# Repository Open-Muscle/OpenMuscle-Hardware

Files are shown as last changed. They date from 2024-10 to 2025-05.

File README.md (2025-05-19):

# 🛠️ OpenMuscle-Hardware (Deprecated)

> ⚠️ **This repository is no longer maintained.**  
> All hardware design files have been **moved to dedicated repositories** for each OpenMuscle device.  
> Please use the links below to access the latest versions, schematics, and BOMs.

---

## 📦 Where to Find Active Repositories

| Device | Description | New Repo |
|---|---|---|
| **FlexGrid** | 60-sensor modular wearable (successor to OM-12) | [OpenMuscle-FlexGrid](https://github.com/Open-Muscle/OpenMuscle-FlexGrid) |
| **LASK5** | Handheld labeler wand for gesture training | [OpenMuscle-LASK5](https://github.com/Open-Muscle/OpenMuscle-LASK5) |
| **OM-12** | Legacy 12-sensor forearm band | [OpenMuscle-Band](https://github.com/Open-Muscle/OpenMuscle-Band) |
| **Firmware & Scripts** | MicroPython code for all devices | [OpenMuscle-Software](https://github.com/Open-Muscle/OpenMuscle-Software) |
| **Documentation** | Central hub with build guides & tutorials | [OpenMuscle-Hub](https://github.com/Open-Muscle/OpenMuscle-Hub) |

---

## 🧬 About This Repo

This repository originally contained hardware design files for two experimental devices:

- **OpenMuscle Labeler** – A handheld interface for labeling finger positions in machine learning datasets.
- **OpenMuscle Sensor Bracelet (OM-12)** – A pressure-based forearm sensor for capturing muscle signals.

These designs are preserved in their new locations above for better modularity and long-term maintainability.

---

## 🧾 Historical Reference

This repo includes:
- `Labeler/`: KiCad files and documents for early LASK prototypes
- `SensorBracelet/`: KiCad files and mechanical designs for OM-12
- `docs/`: Revision notes and changelogs

---

## 📜 License

This repository is licensed under the **CERN-OHL-S v2** (Strongly Reciprocal).

"""markdown
🔗 Learn more at the [Open Source Hardware Association (OSHWA)](https://www.oshwa.org/definition/)
"""

OpenMuscle is an OSHWA-Certified open hardware project  
**Certification UID:** US002537

---

## 🙌 Thank You

Thank you to everyone who starred, forked, contributed to, or studied this repository during its development phase.  
Please visit the [OpenMuscle GitHub Organization](https://github.com/Open-Muscle) to explore the new, modular layout and latest devices.

🧠 Built by [@TURFPTAx](https://github.com/turfptax) • Project home: [openmuscle.org](https://openmuscle.org)

## 🎥 Video Overview

Curious about the assembly process? Watch our detailed video guide covering both the Sensor Bracelet (OM-12) and Labeler (LASK5) builds:  
📺 **[Watch on YouTube](https://www.youtube.com/watch?v=DQQq6cplsOw)**

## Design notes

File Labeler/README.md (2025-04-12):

# LASK5 - A Gloveless Smart Glove Controller





LASK5 is a compact, gloveless smart glove controller designed for robotics, machine learning, and human-computer interaction projects. Originally created to assist with labeling movement data for the [OpenMuscle](https://openmuscle.org) project, this controller is now a fully open-source interface capable of controlling robotic hands, LED sculptures, and more.

---

## 📽️ Watch the Demo

🎥 **YouTube Video:** [LASK5: The Gloveless Smart Glove](https://youtu.be/DJxaf0ww6us)

---

## 🔧 Features

- ESP32-S3 based (Wi-Fi + ESP-NOW enabled)
- 4-piston finger input with hall sensors
- Thumb joystick
- 128x32 OLED display for menus and feedback
- 4 SMD buttons for UI control
- Modular headers for add-ons (gyroscope, additional sensors)
- Written in MicroPython
- 3D-printable enclosure

---

## 📁 Repository Structure

This repo is split into two main components:

### 🛠️ Hardware
📂 [OpenMuscle-Hardware → Labeler](https://github.com/Open-Muscle/OpenMuscle-Hardware/tree/main/Labeler)  
Includes schematics, board files (KiCad), and 3D printable STL files.

### 💾 Software
📂 [OpenMuscle-Software → embedded/Labeler](https://github.com/Open-Muscle/OpenMuscle-Software/tree/main/embedded/Labeler)  
Includes MicroPython source code and menu system.

---

## 🧠 Use Cases

- Robotics hand control (e.g., HiWonder robotic hand)
- LED and art installations
- Machine learning data labeling
- Experimental HCI and VR interface development

---

## 🚀 Getting Started

1. Clone the hardware and software repos.
2. Flash the ESP32-S3 with the provided MicroPython firmware.
3. Assemble the hardware using the STL and PCB files.
4. Power it up and start controlling your devices wirelessly via ESP-NOW!

---

## 🤝 Contribute

Got improvements, ideas, or bug fixes? PRs are welcome!  
If you're using this for your own project, we'd love to see it—tag [@OpenMuscle](https://openmuscle.org)!

---

## 📜 License

This project is open-source and licensed under the MIT License.

---

Made with 💡 by [TURFPTAx](https://github.com/turfptax) for the [OpenMuscle](https://openmuscle.org) initiative.

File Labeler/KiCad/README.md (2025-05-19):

# LASK5 – OpenMuscle Sensor Device

**Version:** `V3 (Proposed)`  
**Target Microcontroller:** ESP32-S3-WROOM-1-N16R8  
**Project:** OpenMuscle – Biomechanical Sensing for Prosthetics & Robotics  
**Repository:** https://github.com/turfptax/OpenMuscle-Hardware

---

## 📐 Overview

The LASK5 board is a wearable sensor platform for real-time finger movement detection, developed as part of the OpenMuscle project. It integrates Hall effect sensors, a joystick, buttons, a low-power screen, and wireless communication via ESP32-S3.

Version 3 introduces multiple improvements in usability, sensing accuracy, and expandability.

---

## 🚀 New in V3 (Proposed)

| Feature | Description |
|---|---|
| 🔌 USB Detection | VBUS now routed to a GPIO via voltage divider, allowing firmware to detect USB connection. |
| 🔋 USB Boot Without Battery | Modified power logic enables powering on via USB without a battery installed, using diode-based OR logic to control LDO enable line. |
| 📉 Improved ADC Accuracy | Voltage divider for battery monitoring updated to 10k/10k, reducing impedance for better ESP32-S3 ADC readings. |
| 🧭 6-Axis Gyroscope Support | IMU footprint and I²C headers added for optional motion sensing (MPU6050 or ICM-42688). |
| ⚙️ Charging Status Feedback | CHRG pin from LTC4054 connected to GPIO for in-software charge status indication. |

---
## 📦 Block Diagram
```
Battery ─────┐
├─> Charger (LTC4054) ──> Power Rail (+3.3V)
USB ───────┐ │
│ └─> VBUS GPIO (USB Detect)
└───> LDO EN Logic ──> TPS7A0333 LDO ──> ESP32-S3
```
---

## 📊 Hardware Specifications

- **MCU:** ESP32-S3-WROOM-1-N16R8 (dual-core, WiFi/BLE, 16MB flash, 8MB PSRAM)
- **Power:**
  - USB-C with VBUS detection
  - 1-cell LiPo battery
  - TPS7A0333 LDO (3.3V, low quiescent current)
  - MAX16054 latched soft-power button
- **Sensing:**
  - 4x Hall effect analog sensors
  - 1x Joystick (XY + button)
  - 0.96” SSD1306 OLED display (I²C)
  - Optional 6-axis gyro (MPU6050, ICM-42688, etc.)
- **Inputs:**
  - `menu` and `select` tactile buttons
  - Power button
- **Charging:**
  - LTC4054ES5-4.2 Li-Ion charger
  - CHRG status indicator routed to GPIO
- **Communication:**
  - ESP-NOW, WiFi, BLE
- **Headers:**
  - I²C breakout
  - SPI/debug/jumper expansion

---

## 🛠️ Setup & Firmware

- Flash via USB-C using esptool or Micropython.
- Default I²C pins: `SDA=GPIO15`, `SCL=GPIO16`
- ADC battery read: `GPIO4` (adjusted via voltage divider)
- USB detect pin: `GPIO10` *(example)*
- CHRG detect pin: `GPIO11` *(example)*

---

## 📚 Resources

- [OpenMuscle.org](https://openmuscle.org)
- [KiCad Schematic Viewer](https://kicad.org)
- [ESP32-S3 Datasheet](https://www.espressif.com/sites/default/files/documentation/esp32-s3_datashee---

## 🙌 Contributing

Interested in testing or improving the hardware? Submit a pull request or open an issue with your suggestions.

---

## 🧪 Version History

| Version | Date | Notes |
|---|---|---|
| V1 | 2024-02 | Initial prototype, using ESP32-S3 Dev-Kit |
| V2 | 2024-05 | 4-Layer PCB with 4x1 Hall sensors & Joystick |
| V3 | 25-XX | USB logic, gyro, and ADC improvements |

---

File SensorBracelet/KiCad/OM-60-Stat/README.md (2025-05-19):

# OpenMuscle FlexGrid (v2.0)

**OpenMuscle FlexGrid** is a modular wearable sensor grid with 60 analog pressure sensors arranged in a 15x4 matrix. It is the second-generation wearable in the OpenMuscle series and serves as the core interface for capturing muscle movement in prosthetic and robotics applications.

📍 Project Page: [openmuscle.org](https://openmuscle.org)

---

## 📐 System Overview

- **Sensor Grid**: 15 columns × 4 rows of Velostat pads
- **Flex PCB**: Thin and wearable with 21-pin output header
- **Rigid PCB**: ESP32-S3, haptic feedback, USB-C charging, multiplexer, OLED, IMU

---

## 🔧 Key Features

| Feature | Description |
|---|---|
| MCU | ESP32-S3 (USB + BLE + ADC1) |
| Sensor Matrix | 15×4 Velostat with voltage divider setup |
| Multiplexer | 74HC4067 (16-channel, 15 used) |
| Row Reads | 4x analog inputs on ADC1 |
| OLED Display | SSD1306 128x32 over I2C |
| IMU | ICM-42688-P 6-DOF sensor (optional) |
| Haptic Feedback | Motor driven by IRLML2060 MOSFET |
| Power Management | MAX16054 soft latch, TPS7A0333 LDO, LTC4054 LiPo charger |

---

## 🗂️ File Structure

```graphql
FlexGrid/
├── KiCad/ # Schematic and layout files
├── Images/ # Renders and photos
├── BOM.xlsx # Bill of materials (optional)
└── README.md # You're reading it!
```

# 📁 Repository Layout

```graphql
OpenMuscle-FlexGrid/
├── firmware/           # MicroPython or C code for scanning and I/O
├── hardware/
│   ├── KiCad/          # Schematics, PCB, BOMs
│   └── Images/         # Renders and assembly diagrams
├── docs/
│   └── Datasheets/     # ICs and reference materials
└── README.md
```
---

## 🛠️ How It Works

The 74HC4067 connects one column at a time to 3.3V. The Velostat pads act as pressure-sensitive resistors connected to row lines, which are pulled down with 10kΩ resistors and read via analog inputs.

A software loop cycles through all 15 columns, sampling all 4 rows each time for 60 total readings per frame.

---

## 🧪 Status

- ✅ Schematic Complete
- ✅ PCB Fabricated & Assembled
- 🛠️ Firmware In Progress
- 🧠 ML Integration Pipeline Active

---

## 🔗 Related Projects

- [SensorBracelet (OM-12)](../SensorBracelet/)
- [Labeler (LASK5)](../Labeler/)

---

## 📝 License

- **Hardware**: CERN-OHL-P v2
- **Software/Firmware**: MIT

---

## 🤝 Get Involved

We welcome contributions, feedback, and forks. This project is part of a broader mission to open-source biomechanical sensing tools for all.

Visit **[openmuscle.org](https://openmuscle.org)** or join our Discord (link coming soon).

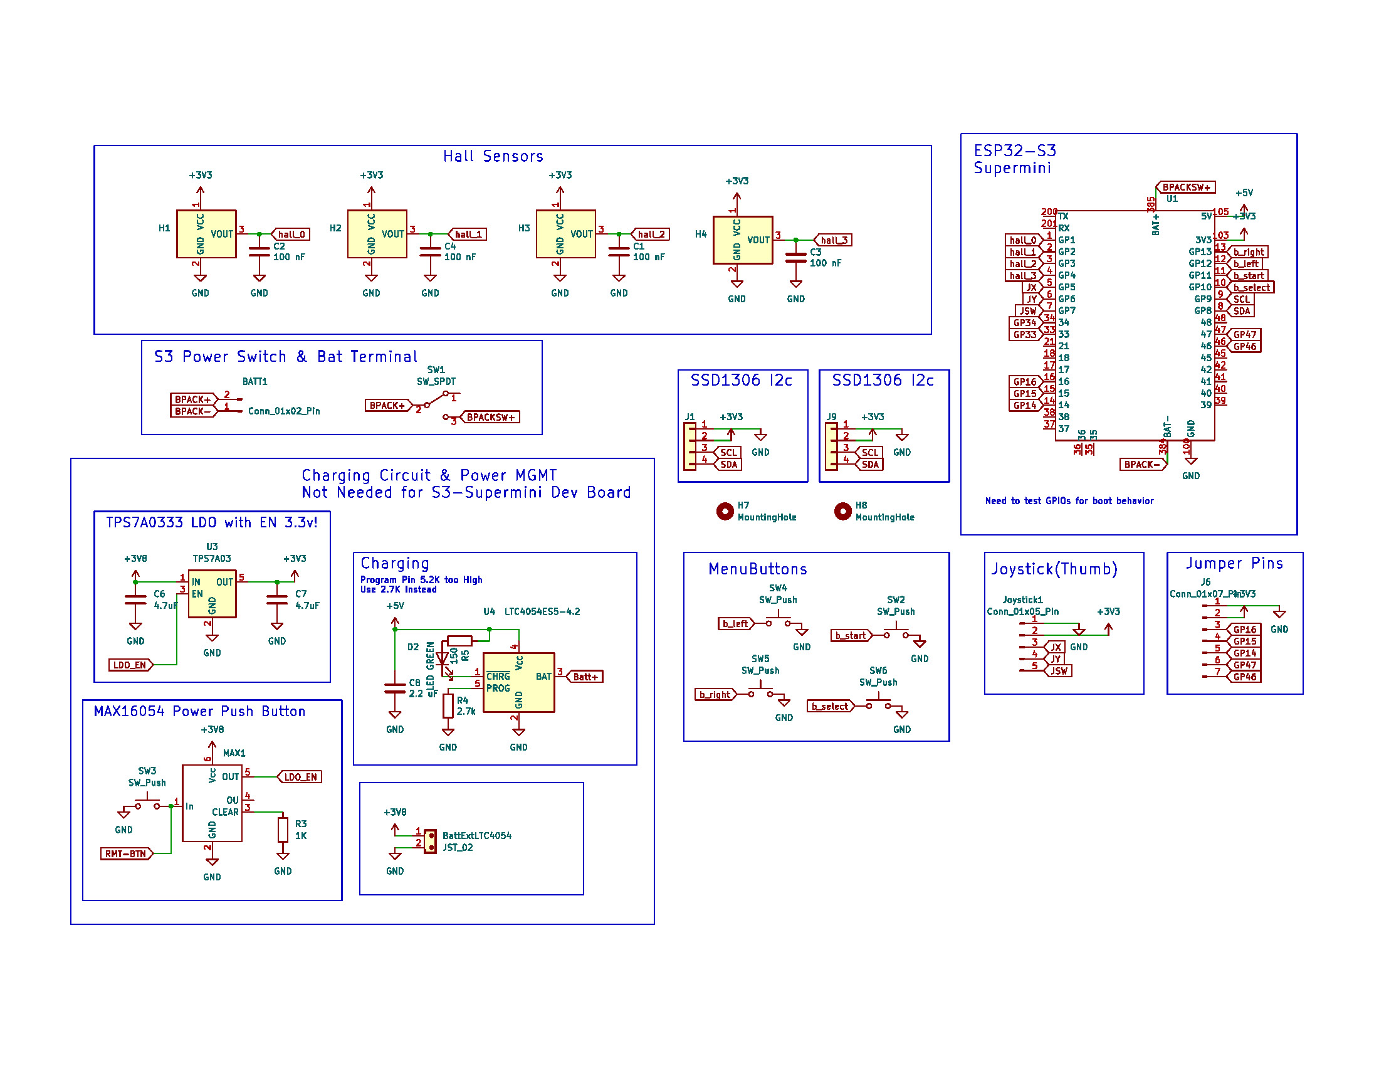
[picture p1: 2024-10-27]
Labeler/Schematics/Open Muscle Labeler (LASK5) Schematic.jpg

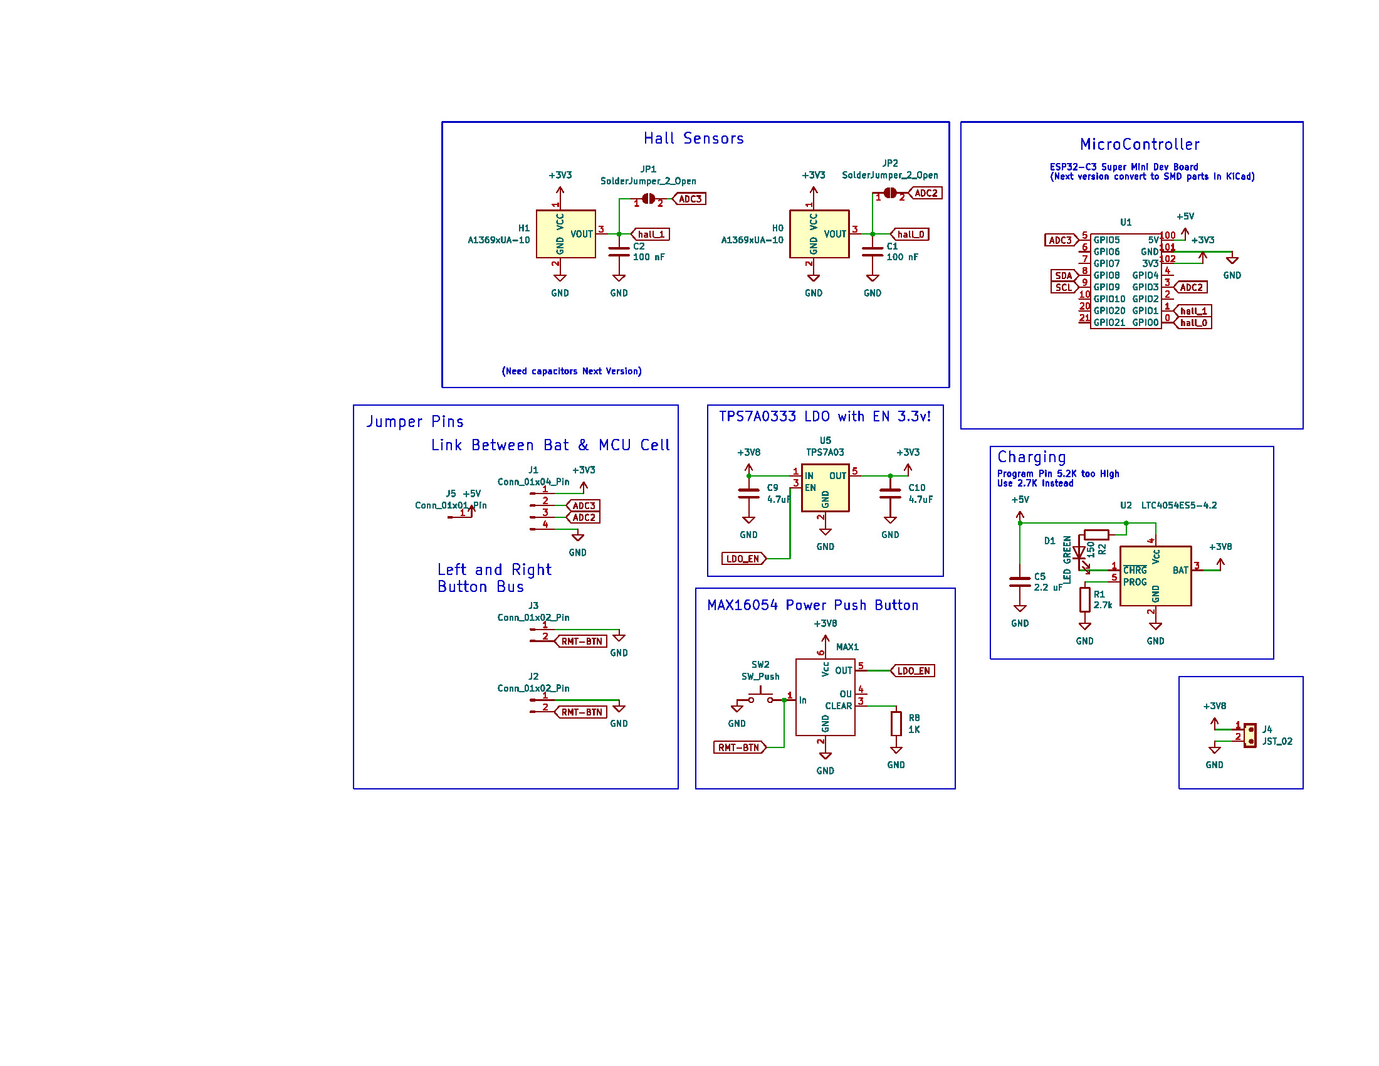
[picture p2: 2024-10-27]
SensorBracelet/Schematics/Open Muscle Dev Kit Bracelet Cell Schematic.jpg

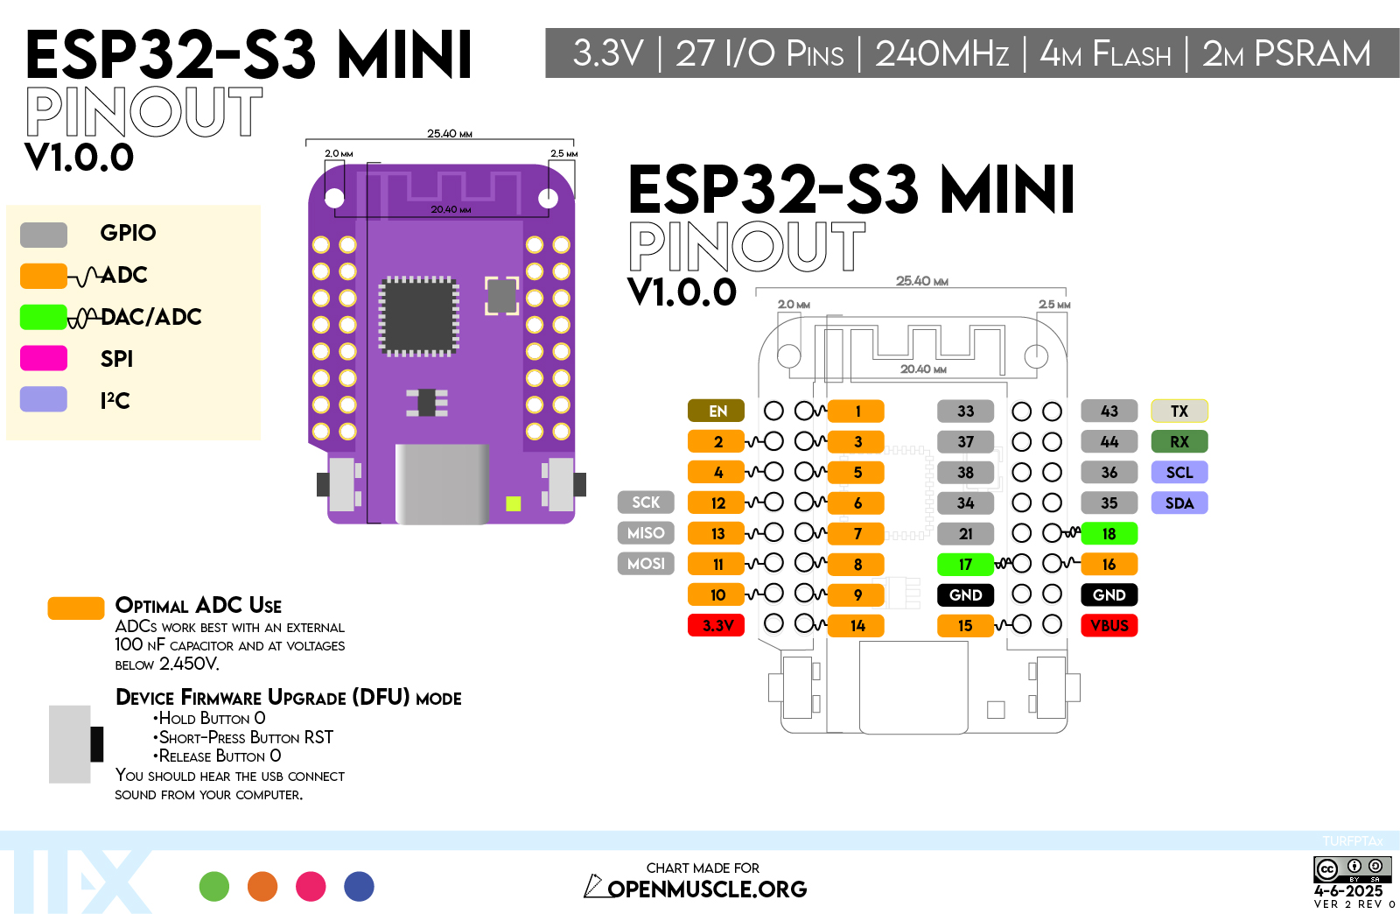
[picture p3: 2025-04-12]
images/ESP32_S3_mini_V2R0-01.jpg

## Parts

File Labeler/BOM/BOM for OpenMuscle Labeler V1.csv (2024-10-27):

Id | Designator | Footprint | Quantity | Designation | Supplier and ref | Supplier Link | Prototype Source
1 | C2,C4,C3,C1 | C_0402_1005Metric | 4 | 100 nF
2 | R4 | R_0603_1608Metric | 1 | 2.7k
3 | C6,C7 | C_0805_2012Metric | 2 | 4.7uF
4 | U4 | TSOT-23-5 | 1 | LTC4054ES5-4.2 | Mouser 584-C4054LES5-4.2TPF
5 | SW4,SW3,SW6,SW5,SW2 | EVQP2P02M | 5 | SW_Push | Mouser 667-EVQ-P2P02M
6 | J9,J1 | PinHeader_1x04_P2.54mm_Vertical | 2 | Conn_01x04
7 | Joystick1 | PinHeader_1x05_P2.54mm_Vertical | 1 | Conn_01x05_Pin
8 | H2,H4,H1,H3 | PinHeader_1x03_P2.00mm_Vertical | 4 | A1369xUA-10 | Mouser 621-AH49EZ3-G1 | https://www.mouser.com/ProductDetail/Diodes-Incorporated/AH49EZ3-G1?qs=5V6w%252Be2aIqZwPNuykKDe4Q%3D%3D | Amazon https://www.amazon.com/dp/B09MSDC3GR?ref=ppx_yo2ov_dt_b_fed_asin_title
9 | C8 | C_0603_1608Metric | 1 | 2.2 uF
10 | U3 | SOT-23-5 | 1 | TPS7A03
11 | R3 | R_0603_1608Metric | 1 | 1K
12 | H8,H7 | MountingHole_2.2mm_M2 | 2 | MountingHole
13 | SW1 | PinHeader_1x03_P2.54mm_Vertical | 1 | SW_SPDT
14 | J6 | PinHeader_1x07_P2.54mm_Vertical | 1 | Conn_01x07_Pin
15 | BattExtLTC4054 | JST_EH_B2B-EH-A_1x02_P2.50mm_Vertical | 1 | JST_02
16 | D2 | LED_0805_2012Metric | 1 | LED GREEN
17 | R5 | R_0603_1608Metric | 1 | 150
18 | U1 | ESP32-S3-Super Mini | 1 | ~
19 | MAX1 | SOT-23-6 | 1 | ~
20 | BATT1 | PinHeader_1x02_P2.54mm_Vertical | 1 | Conn_01x02_Pin
21 | SSD1306 |  |  | SSD1306 128x32 |  |  | https://www.amazon.com/dp/B08LQM9PQQ?ref=ppx_yo2ov_dt_b_fed_asin_title
22 | ESP32-S3 Supermini |  |  | ESP32 SuperMini development board | Aliexpress | https://www.aliexpress.us/item/3256807383269389.html | Amazon https://www.amazon.com/dp/B0CW62PPZ1?ref=ppx_yo2ov_dt_b_fed_asin_title
23 | 2M machine screws |  | 6 | DIN7985 2M x 6mm |  | https://www.aliexpress.us/item/3256804074121536.html
24 | 2M Brass threaded Insert |  | 6 | M2x3x3.5mm |  |  | https://www.amazon.com/gp/product/B0B8GN63S2/ref=ppx_yo_dt_b_search_asin_title?ie=UTF8&psc=1
25 | Dual Axis Joystick |  | 1 |  |  |  | amazon https://www.amazon.com/dp/B0BX6FMC2H?ref=ppx_yo2ov_dt_b_fed_asin_title

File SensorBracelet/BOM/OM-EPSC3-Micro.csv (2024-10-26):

Id | Designator | Footprint | Quantity | Designation | Supplier and ref
1 | J5 | PinHeader_1x01_P2.54mm_Vertical | 1 | Conn_01x01_Pin
2 | R2 | R_0603_1608Metric | 1 | 150
3 | H1,H0 | Hall49E | 2 | A1369xUA-10
4 | U5 | SOT-23-5 | 1 | TPS7A03
5 | JP1,JP2 | SolderJumper-2_P1.3mm_Open_TrianglePad1.0x1.5mm | 2 | SolderJumper_2_Open
6 | U2 | TSOT-23-5 | 1 | LTC4054ES5-4.2
7 | J3,J2 | PinHeader_1x02_P2.54mm_Vertical | 2 | Conn_01x02_Pin
8 | C1,C2 | C_0402_1005Metric | 2 | 100 nF
9 | C9,C10 | C_0805_2012Metric | 2 | 4.7uF
10 | J1 | PinHeader_1x04_P2.54mm_Vertical | 1 | Conn_01x04_Pin
11 | D1 | LED_0805_2012Metric | 1 | LED GREEN
12 | R1 | R_0603_1608Metric | 1 | 2.7k
13 | U1 | ESP32-C3-Super Mini | 1 | ~
14 | R8 | R_0603_1608Metric | 1 | 1K
15 | J4 | JST_EH_B2B-EH-A_1x02_P2.50mm_Vertical | 1 | JST_02
16 | SW2 | EVQP2P02M | 1 | SW_Push
17 | C5 | C_0603_1608Metric | 1 | 2.2 uF
18 | MAX1 | SOT-23-6 | 1 | ~

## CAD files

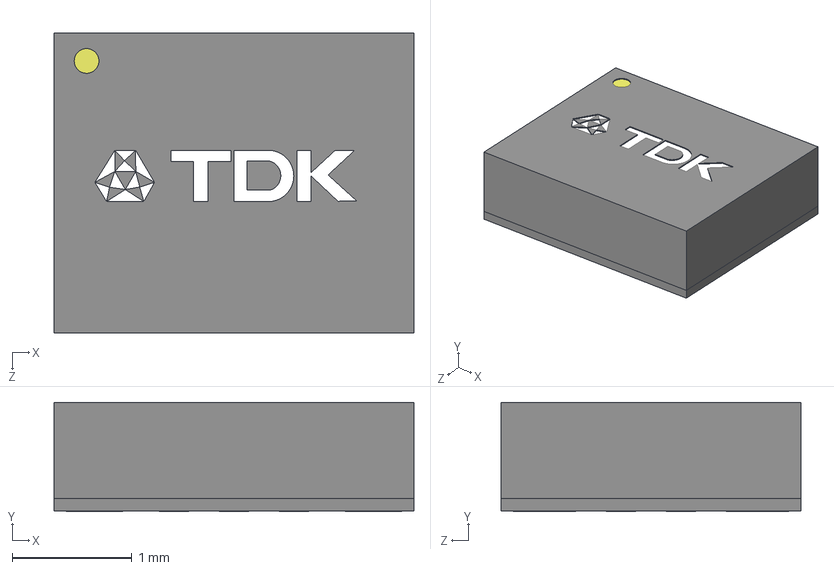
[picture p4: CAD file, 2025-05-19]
Labeler/KiCad/ICM-42688-P/ICM-42688-P/3D/ICM-42688-P.stp
3.00 x 0.91 x 2.50 mm

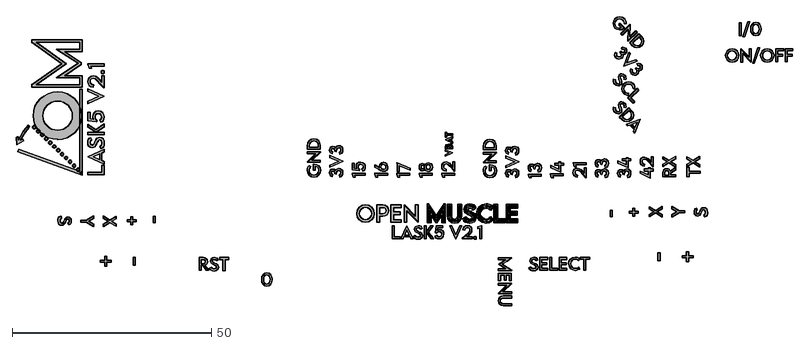
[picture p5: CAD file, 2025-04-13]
Labeler/KiCad/LASK_V3-0/LASK5-2-1-Design-TESTTTT.dxf
195.0 x 72.7

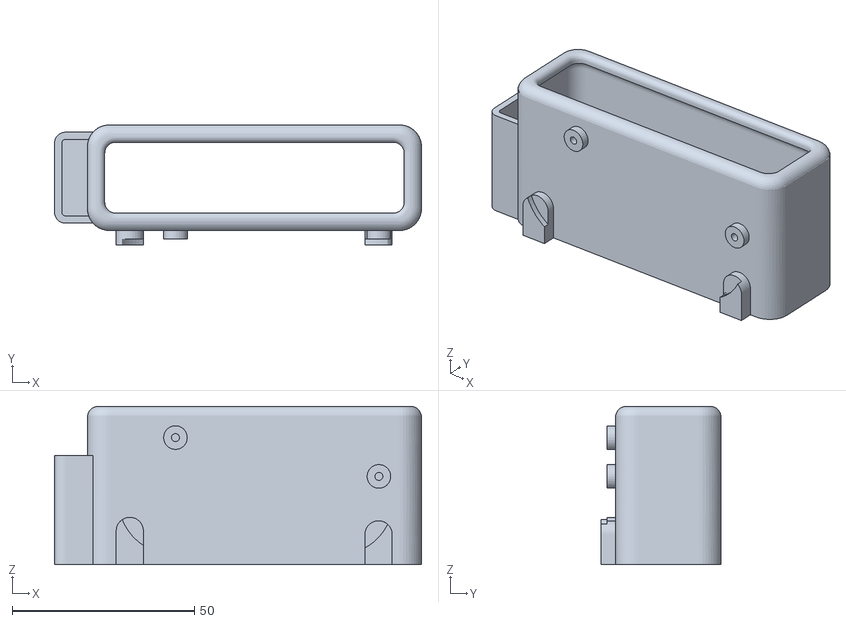
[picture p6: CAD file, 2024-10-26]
Labeler/STLs/LASK5-BatteryHolder.stl
100.8 x 33.0 x 43.5

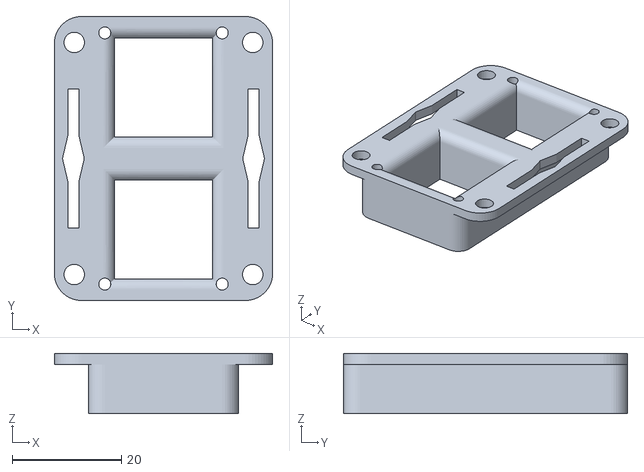
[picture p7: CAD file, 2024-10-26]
SensorBracelet/STLs/OMCellCover.stl
40.0 x 52.0 x 11.0

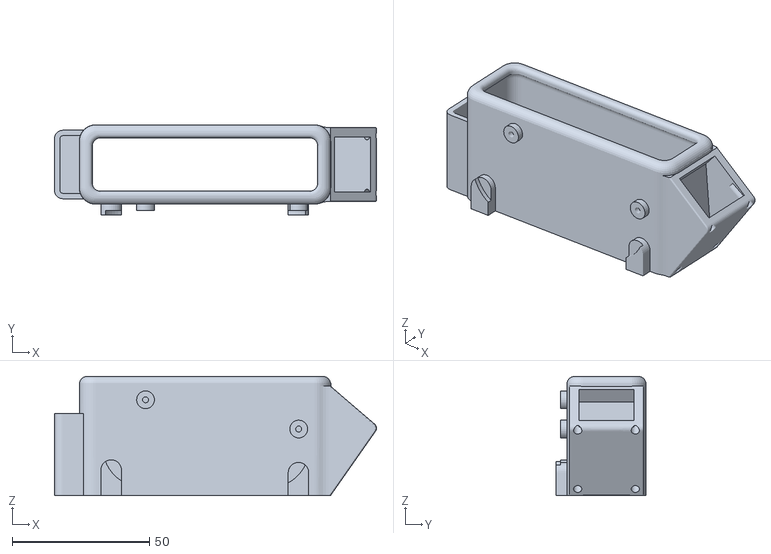
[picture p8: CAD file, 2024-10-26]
Labeler/STLs/LASK5-JoyThumb.stl
117.5 x 33.0 x 43.6

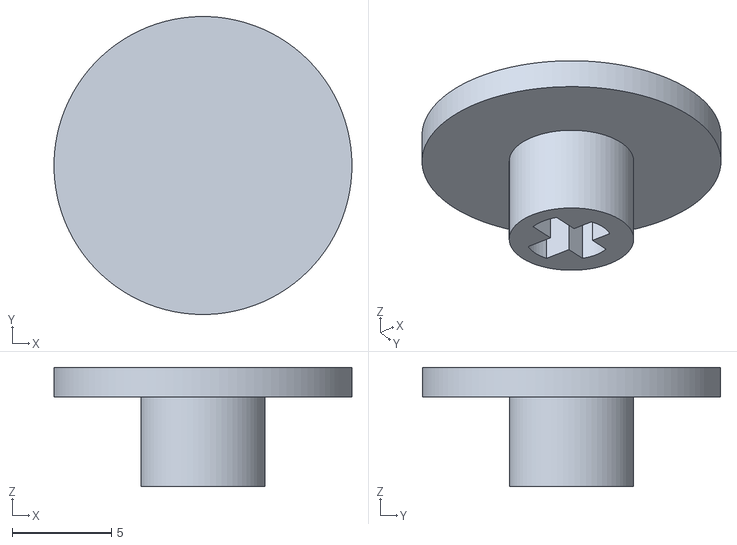
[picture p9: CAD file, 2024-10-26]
SensorBracelet/STLs/SwitchCapFeet.stl
15.0 x 15.0 x 6.00

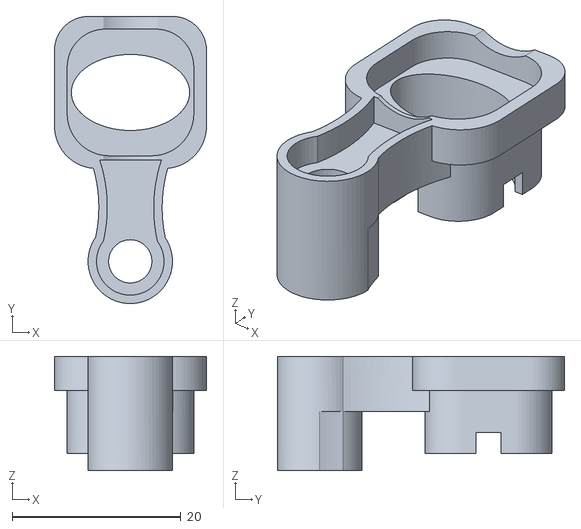
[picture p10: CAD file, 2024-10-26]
Labeler/STLs/Labeler Depressor.stl
18.0 x 34.0 x 13.5

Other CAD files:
Labeler/KiCad/ICM-42688-P/ICM-42688-P/Allegro/iim42352.psm
Labeler/KiCad/ICM-42688-P/ICM-42688-P/DEHDL/icm_42688_p/chips/chips.prt

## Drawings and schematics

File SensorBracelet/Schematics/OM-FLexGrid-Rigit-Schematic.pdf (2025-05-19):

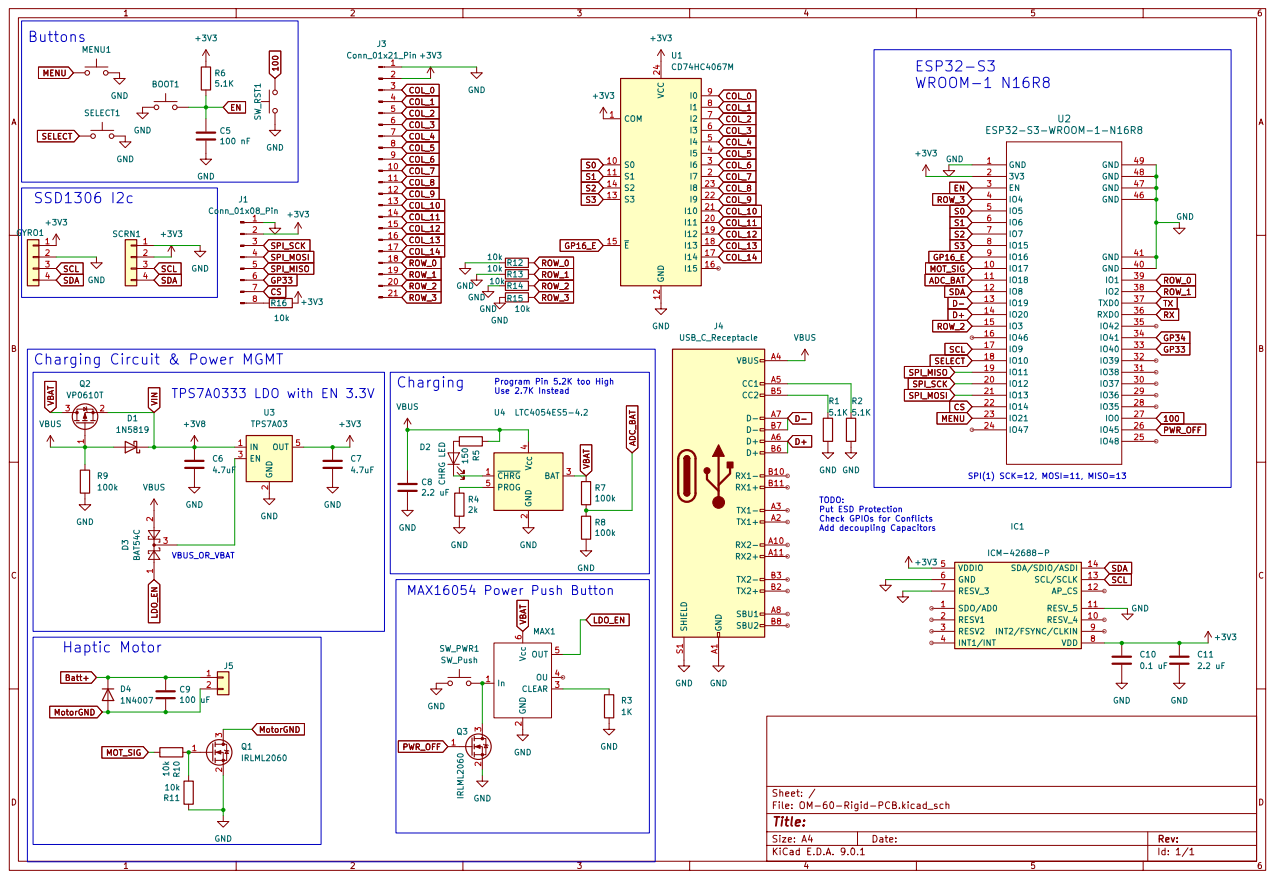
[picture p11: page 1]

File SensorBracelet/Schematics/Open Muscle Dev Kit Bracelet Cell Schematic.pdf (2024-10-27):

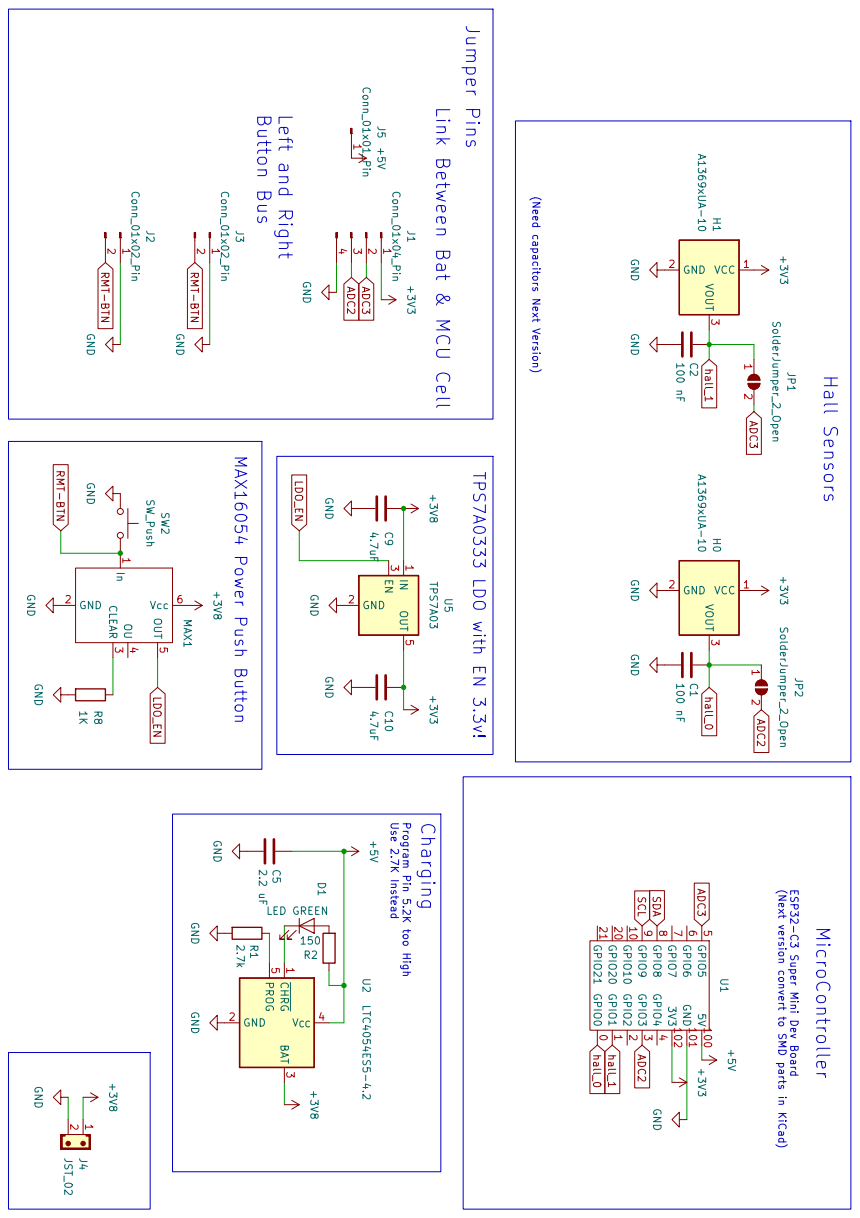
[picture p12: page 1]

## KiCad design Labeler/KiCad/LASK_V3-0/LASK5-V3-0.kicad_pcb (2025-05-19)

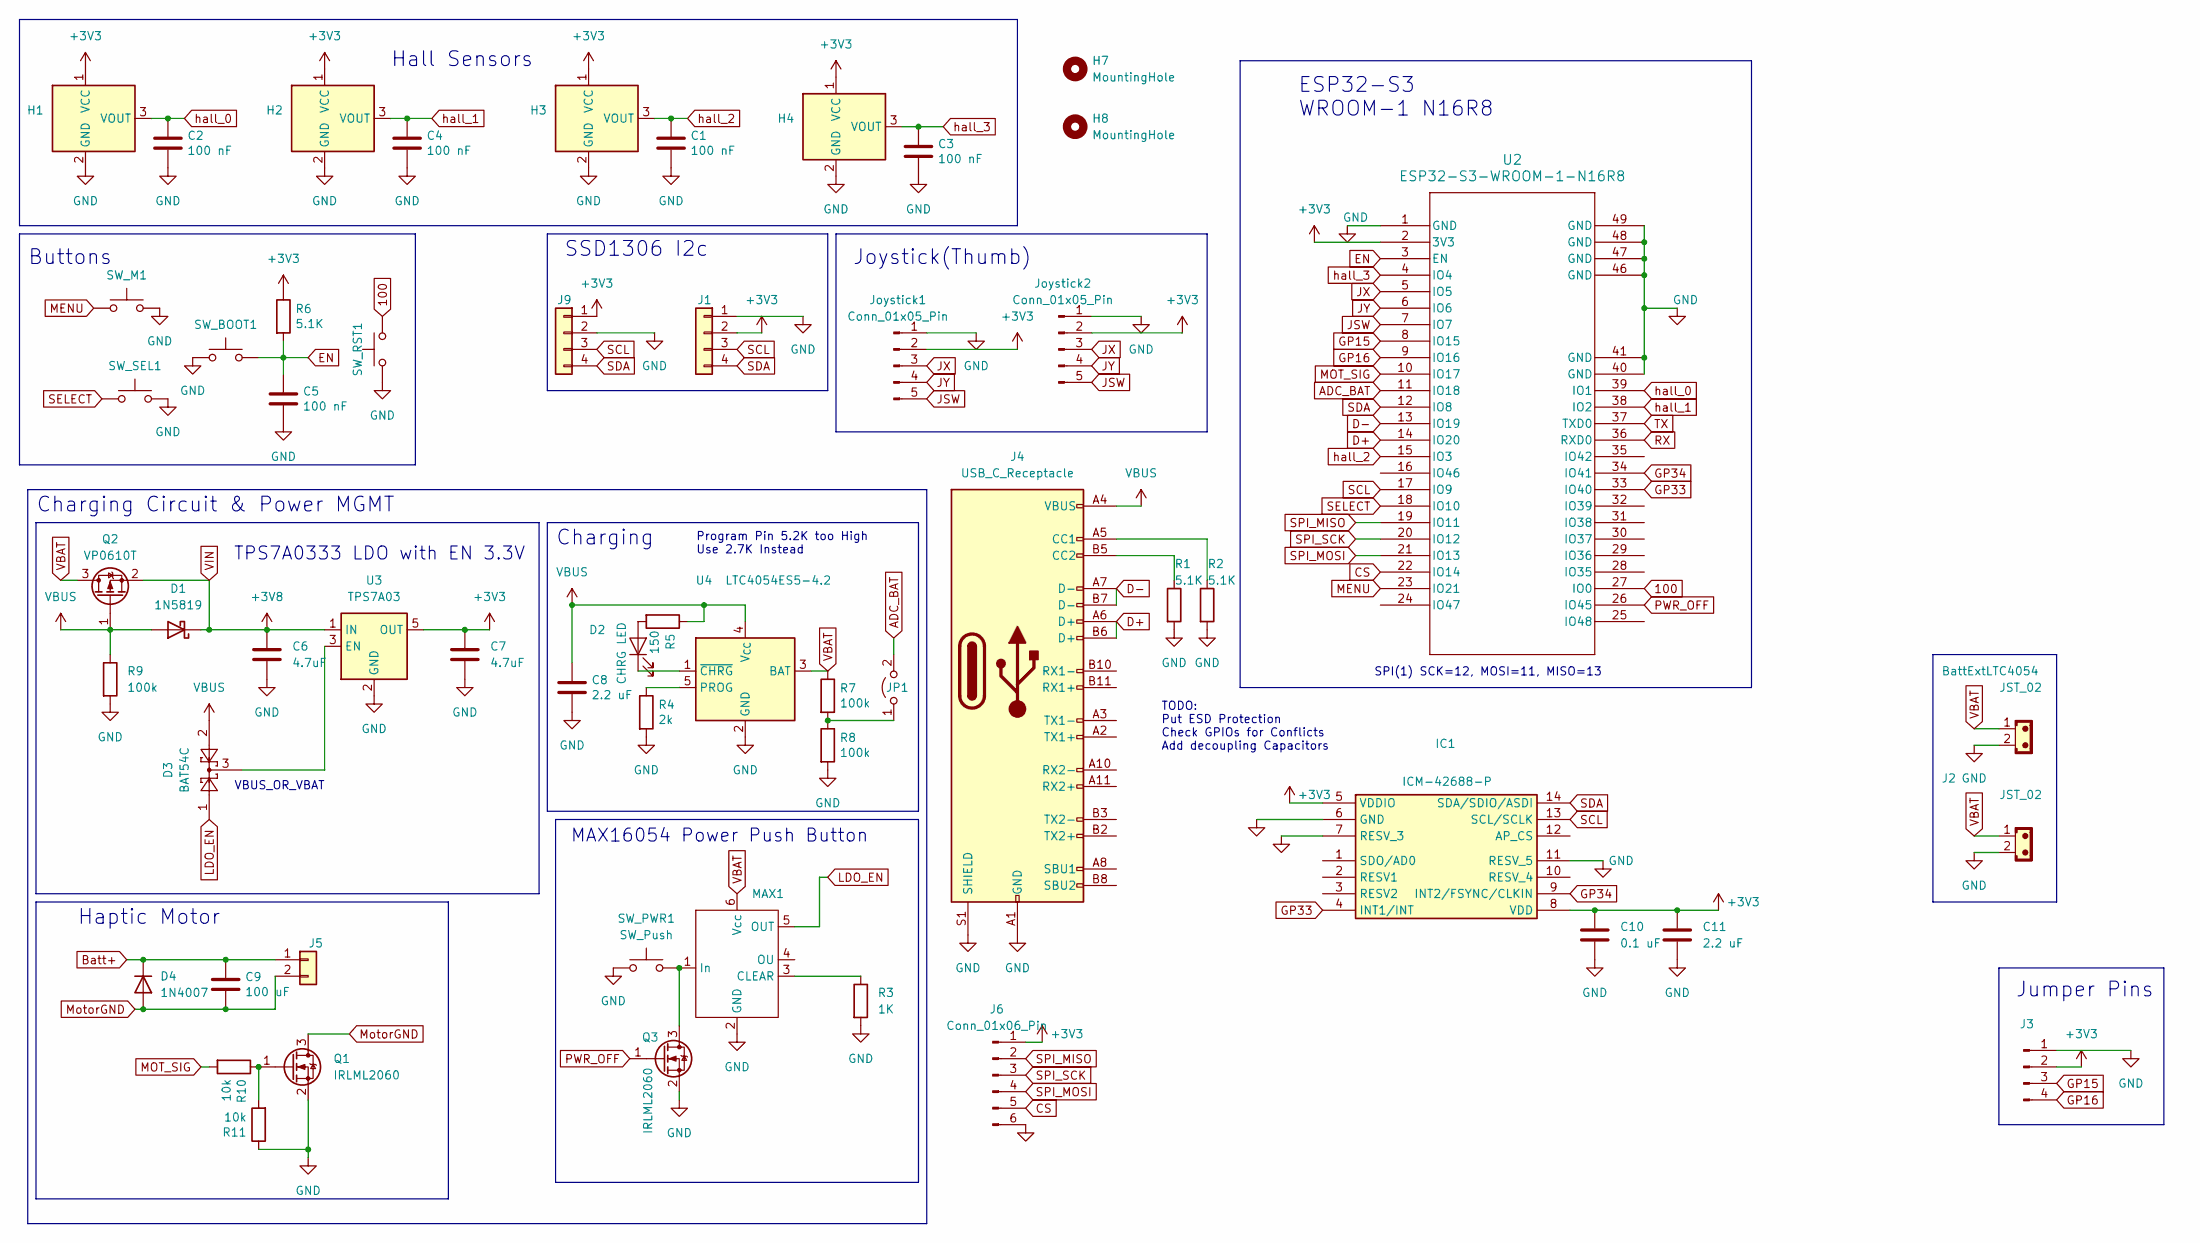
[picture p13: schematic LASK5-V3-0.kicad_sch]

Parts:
BattExtLTC4054: JST_02; JST_EH_B2B-EH-A_1x02_P2.50mm_Vertical
C1, C2, C3, C4, C5: 100 nF; C_0402_1005Metric; JLCPN C1525
C6, C7: 4.7uF; C_0805_2012Metric
C8: 2.2 uF; C_0603_1608Metric; JLCPN C12530
C9: 100 uF; C_0603_1608Metric; JLCPN C12530
C10: 0.1 uF; C_0603_1608Metric
C11: 2.2 uF; C_0603_1608Metric
D1: 1N5819; D_SOD-123F
D2: CHRG LED; LED_0805_2012Metric; JLCPN C72043
D3: BAT54C; SOT-23
D4: 1N4007; D_SOD-123
H1, H2, H3, H4: A1369xUA-10; PinHeader_1x03_P2.00mm_Vertical
H7, H8: MountingHole; MountingHole_2.2mm_M2
IC1: ICM-42688-P; IIM42352; Mouser Part Number 410-ICM-42688-P
J1, J9: Conn_01x04; PinHeader_1x04_P2.54mm_Vertical
J2: JST_02; JST_EH_B2B-EH-A_1x02_P2.50mm_Vertical
J3: Conn_01x04_Pin; PinHeader_1x04_P2.00mm_Vertical
J4: USB_C_Receptacle; USB_C_Receptacle_HRO_TYPE-C-31-M-12
J5: Conn_01x02; PinHeader_1x02_P2.00mm_Vertical
J6: Conn_01x06_Pin; PinHeader_1x06_P1.27mm_Vertical
JP1: Jumper_2_Open; SolderJumper-2_P1.3mm_Open_TrianglePad1.0x1.5mm
Joystick1, Joystick2: Conn_01x05_Pin; PinHeader_1x05_P2.00mm_Vertical
MAX1: SOT-23-6
Q1, Q3: IRLML2060; SOT-23
Q2: VP0610T; SOT-23
R1, R2, R6: 5.1K; R_0603_1608Metric; JLCPN C25905
R3: 1K; R_0603_1608Metric
R4: 2k; R_0603_1608Metric; JLCPN C25905
R5: 150; R_0603_1608Metric; JLCPN C4109
R7, R8: 100k; R_0603_1608Metric; JLCPN C25905
R9: 100k; R_0603_1608Metric
R10, R11: 10k; R_0603_1608Metric; JLCPN C25744
SW_BOOT1: SW_Push; EVQP2P02M
SW_M1: SW_Push; EVQP2P02M
SW_PWR1: SW_Push; EVQP2P02M
SW_RST1: SW_Push; EVQP2P02M
SW_SEL1: SW_Push; EVQP2P02M
U2: ESP32-S3-WROOM-1-N16R8; ESP32-S3-WROOM-1_EXP
U3: TPS7A03; SOT-23-5
U4: LTC4054ES5-4.2; TSOT-23-5

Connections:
100: SW_RST1.2, U2.27 (IO0)
+3V3: C7.1, C10.1, C11.1, H1.1 (VCC), H2.1 (VCC), H3.1 (VCC), H4.1 (VCC), IC1.5 (VDDIO), IC1.8 (VDD), J1.2, J3.2, J6.1, J9.1, Joystick1.2, Joystick2.2, R6.1, U2.2 (3V3), U3.5 (OUT)
ADC_BAT: JP1.2 (B), U2.11 (IO18)
Batt+: C9.2, D4.1 (K), J5.1
CS: J6.5, U2.22 (IO14)
D+: J4.A6 (D+), J4.B6 (D+), U2.14 (IO20)
D-: J4.A7 (D-), J4.B7 (D-), U2.13 (IO19)
EN: C5.2, R6.2, SW_BOOT1.2, U2.3 (EN)
GND: BattExtLTC4054.2, C1.1, C2.1, C3.1, C4.1, C5.1, C6.2, C7.2, C8.1, C10.2, C11.2, H1.2 (GND), H2.2 (GND), H3.2 (GND), H4.2 (GND), IC1.6 (GND), IC1.7 (RESV_3), IC1.11 (RESV_5), J1.1, J2.2, J3.1, J4.A1 (GND), J4.A12 (GND), J4.B1 (GND), J4.B12 (GND), J4.S1 (SHIELD), J6.6, J9.2, Joystick1.1, Joystick2.1, MAX1.2 (GND), Q1.2 (S), Q3.2 (S), R1.2, R2.2, R3.2, R4.2, R8.2, R9.2, R11.1, SW_BOOT1.1, SW_M1.2, SW_PWR1.1, SW_RST1.1, SW_SEL1.2, U2.1 (GND), U2.40 (GND), U2.41 (GND), U2.46 (GND), U2.47 (GND), U2.48 (GND), U2.49 (GND), U3.2 (GND), U4.2 (GND)
GP15: J3.3, U2.8 (IO15)
GP16: J3.4, U2.9 (IO16)
GP33: IC1.4 (INT1/INT), U2.33 (IO40)
GP34: IC1.9 (INT2/FSYNC/CLKIN), U2.34 (IO41)
JSW: Joystick1.5, Joystick2.5, U2.7 (IO7)
JX: Joystick1.3, Joystick2.3, U2.5 (IO5)
JY: Joystick1.4, Joystick2.4, U2.6 (IO6)
LDO_EN: D3.1, MAX1.5 (OUT)
MENU: SW_M1.1, U2.23 (IO21)
MOT_SIG: R10.2, U2.10 (IO17)
MotorGND: C9.1, D4.2 (A), J5.2, Q1.3 (D)
unnamed: D2.2 (A), R5.2
unnamed: D2.1 (K), U4.1 (~CHRG)
unnamed: J4.A5 (CC1), R2.1
unnamed: J4.B5 (CC2), R1.1
unnamed: JP1.1 (A), R7.2, R8.1
unnamed: MAX1.3 (CLEAR), R3.1
unnamed: MAX1.1 (In), Q3.3 (D), SW_PWR1.2
unnamed: Q1.1 (G), R10.1, R11.2
unnamed: D3.3, U3.3 (EN)
unnamed: R4.1, U4.5 (PROG)
PWR_OFF: Q3.1 (G), U2.26 (IO45)
RX: U2.36 (RXD0)
SCL: IC1.13 (SCL/SCLK), J1.3, J9.3, U2.17 (IO9)
SDA: IC1.14 (SDA/SDIO/ASDI), J1.4, J9.4, U2.12 (IO8)
SELECT: SW_SEL1.1, U2.18 (IO10)
SPI_MISO: J6.2, U2.19 (IO11)
SPI_MOSI: J6.4, U2.21 (IO13)
SPI_SCK: J6.3, U2.20 (IO12)
TX: U2.37 (TXD0)
VBAT: BattExtLTC4054.1, J2.1, MAX1.6 (Vcc), Q2.3 (D), R7.1, U4.3 (BAT)
VBUS: C8.2, D1.2 (A), D3.2, J4.A4 (VBUS), J4.A9 (VBUS), J4.B4 (VBUS), J4.B9 (VBUS), Q2.1 (G), R5.1, R9.1, U4.4 (V_{CC})
VIN: C6.1, D1.1 (K), Q2.2 (S), U3.1 (IN)
hall_0: C2.2, H1.3 (VOUT), U2.39 (IO1)
hall_1: C4.2, H2.3 (VOUT), U2.38 (IO2)
hall_2: C1.2, H3.3 (VOUT), U2.15 (IO3)
hall_3: C3.2, H4.3 (VOUT), U2.4 (IO4)

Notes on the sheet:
Jumper Pins
SPI(1) SCK=12, MOSI=11, MISO=13
Buttons
MAX16054 Power Push Button
Joystick(Thumb)
Program Pin 5.2K too High Use 2.7K Instead
Charging
ESP32-S3 WROOM-1 N16R8
Charging Circuit & Power MGMT
SSD1306 I2c
TODO: Put ESD Protection Check GPIOs for Conflicts Add decoupling Capacitors
TPS7A0333 LDO with EN 3.3V
Hall Sensors
VBUS_OR_VBAT
Haptic Motor

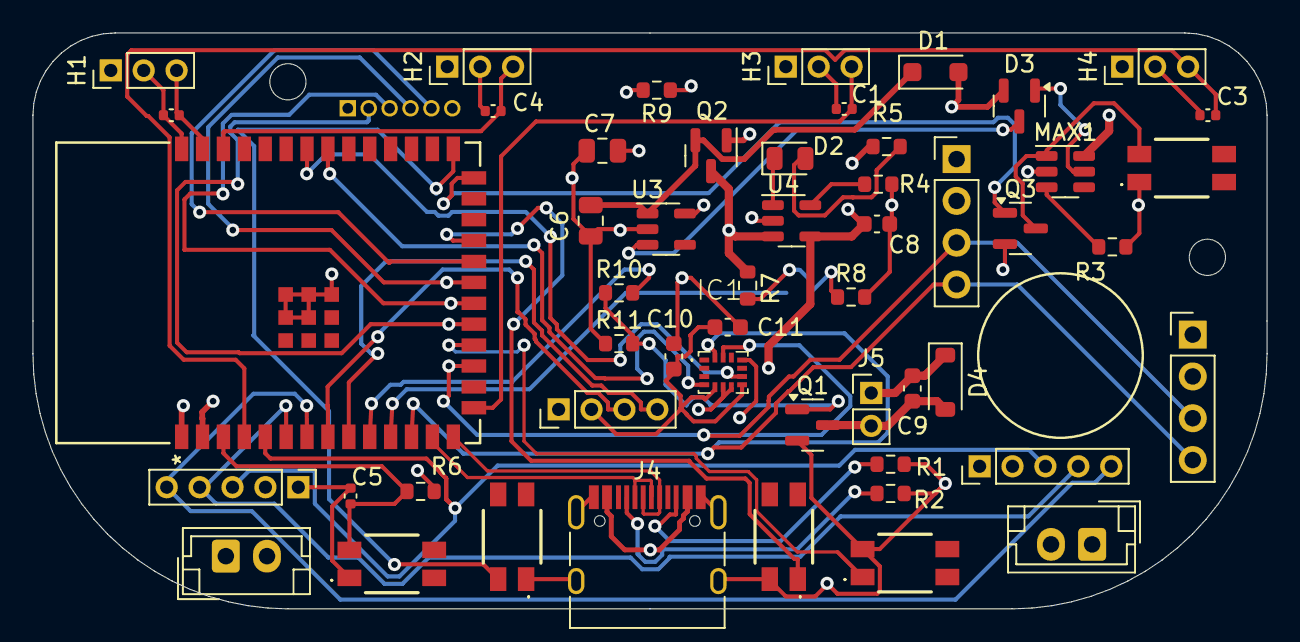
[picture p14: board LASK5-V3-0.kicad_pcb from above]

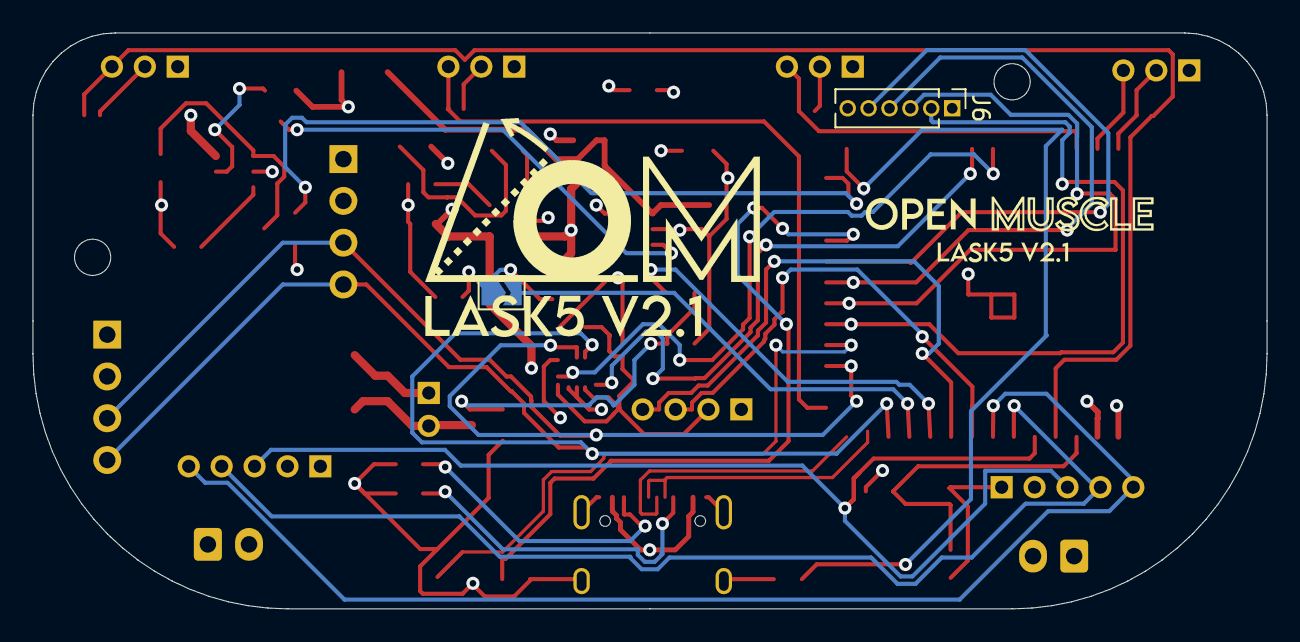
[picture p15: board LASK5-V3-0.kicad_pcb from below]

Board: 4 copper layers, 75.0 x 35.0 mm, 56 parts (2 on the bottom side), 44 nets.

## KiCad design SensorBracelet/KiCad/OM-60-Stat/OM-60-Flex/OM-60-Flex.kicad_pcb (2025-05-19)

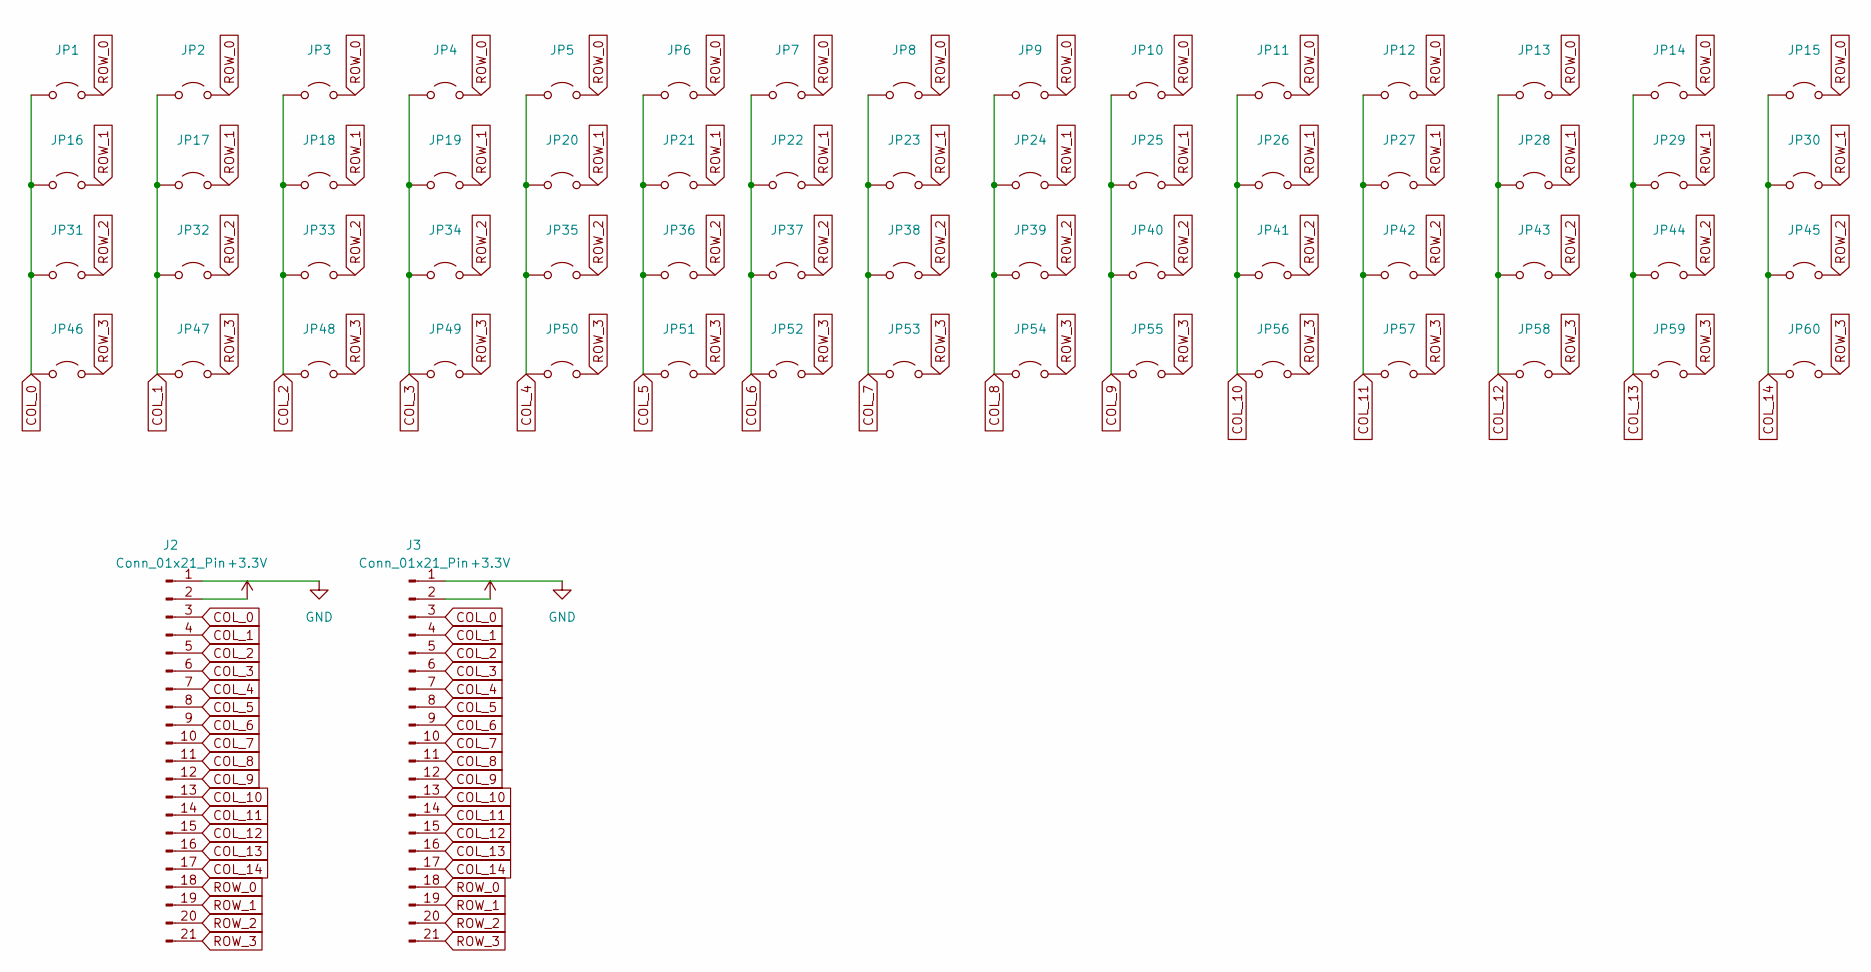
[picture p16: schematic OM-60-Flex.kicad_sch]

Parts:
J2, J3: Conn_01x21_Pin; PinSocket_1x21_P2.54mm_Vertical
JP1, JP2, JP3, JP4, JP5, JP6, JP7, JP8, JP9, JP10, JP11, JP12, JP13, JP14, JP15, JP16, JP17, JP18, JP19, JP20, JP21, JP22, JP23, JP24, JP25, JP26, JP27, JP28, JP29, JP30, JP31, JP32, JP33, JP34, JP35, JP36, JP37, JP38, JP39, JP40, JP41, JP42, JP43, JP44, JP45, JP46, JP47, JP48, JP49, JP50, JP51, JP52, JP53, JP54, JP55, JP56, JP57, JP58, JP59, JP60: Jumper_2_Open; 10mmPad

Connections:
+3.3V: J2.2, J3.2
COL_0: J2.3, J3.3, JP1.1 (A), JP16.1 (A), JP31.1 (A), JP46.1 (A)
COL_1: J2.4, J3.4, JP2.1 (A), JP17.1 (A), JP32.1 (A), JP47.1 (A)
COL_2: J2.5, J3.5, JP3.1 (A), JP18.1 (A), JP33.1 (A), JP48.1 (A)
COL_3: J2.6, J3.6, JP4.1 (A), JP19.1 (A), JP34.1 (A), JP49.1 (A)
COL_4: J2.7, J3.7, JP5.1 (A), JP20.1 (A), JP35.1 (A), JP50.1 (A)
COL_5: J2.8, J3.8, JP6.1 (A), JP21.1 (A), JP36.1 (A), JP51.1 (A)
COL_6: J2.9, J3.9, JP7.1 (A), JP22.1 (A), JP37.1 (A), JP52.1 (A)
COL_7: J2.10, J3.10, JP8.1 (A), JP23.1 (A), JP38.1 (A), JP53.1 (A)
COL_8: J2.11, J3.11, JP9.1 (A), JP24.1 (A), JP39.1 (A), JP54.1 (A)
COL_9: J2.12, J3.12, JP10.1 (A), JP25.1 (A), JP40.1 (A), JP55.1 (A)
COL_10: J2.13, J3.13, JP11.1 (A), JP26.1 (A), JP41.1 (A), JP56.1 (A)
COL_11: J2.14, J3.14, JP12.1 (A), JP27.1 (A), JP42.1 (A), JP57.1 (A)
COL_12: J2.15, J3.15, JP13.1 (A), JP28.1 (A), JP43.1 (A), JP58.1 (A)
COL_13: J2.16, J3.16, JP14.1 (A), JP29.1 (A), JP44.1 (A), JP59.1 (A)
COL_14: J2.17, J3.17, JP15.1 (A), JP30.1 (A), JP45.1 (A), JP60.1 (A)
GND: J2.1, J3.1
ROW_0: J2.18, J3.18, JP1.2 (B), JP2.2 (B), JP3.2 (B), JP4.2 (B), JP5.2 (B), JP6.2 (B), JP7.2 (B), JP8.2 (B), JP9.2 (B), JP10.2 (B), JP11.2 (B), JP12.2 (B), JP13.2 (B), JP14.2 (B), JP15.2 (B)
ROW_1: J2.19, J3.19, JP16.2 (B), JP17.2 (B), JP18.2 (B), JP19.2 (B), JP20.2 (B), JP21.2 (B), JP22.2 (B), JP23.2 (B), JP24.2 (B), JP25.2 (B), JP26.2 (B), JP27.2 (B), JP28.2 (B), JP29.2 (B), JP30.2 (B)
ROW_2: J2.20, J3.20, JP31.2 (B), JP32.2 (B), JP33.2 (B), JP34.2 (B), JP35.2 (B), JP36.2 (B), JP37.2 (B), JP38.2 (B), JP39.2 (B), JP40.2 (B), JP41.2 (B), JP42.2 (B), JP43.2 (B), JP44.2 (B), JP45.2 (B)
ROW_3: J2.21, J3.21, JP46.2 (B), JP47.2 (B), JP48.2 (B), JP49.2 (B), JP50.2 (B), JP51.2 (B), JP52.2 (B), JP53.2 (B), JP54.2 (B), JP55.2 (B), JP56.2 (B), JP57.2 (B), JP58.2 (B), JP59.2 (B), JP60.2 (B)

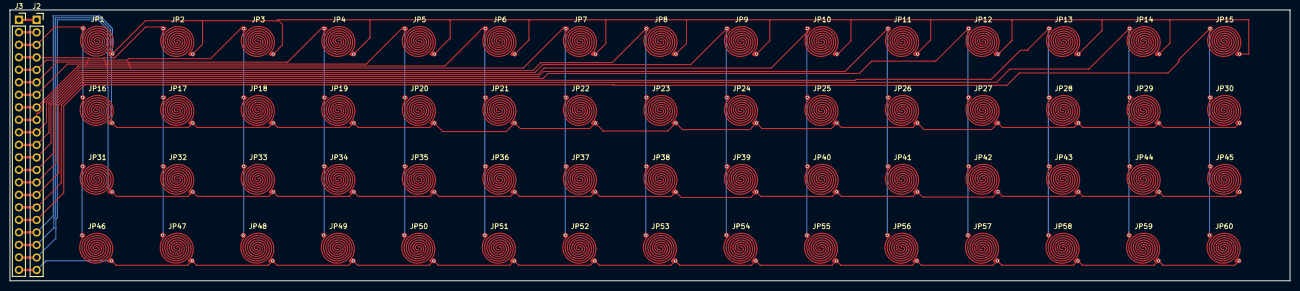
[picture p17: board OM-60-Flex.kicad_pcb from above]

Board: 2 copper layers, 260.0 x 55.0 mm, 62 parts (0 on the bottom side), 21 nets.

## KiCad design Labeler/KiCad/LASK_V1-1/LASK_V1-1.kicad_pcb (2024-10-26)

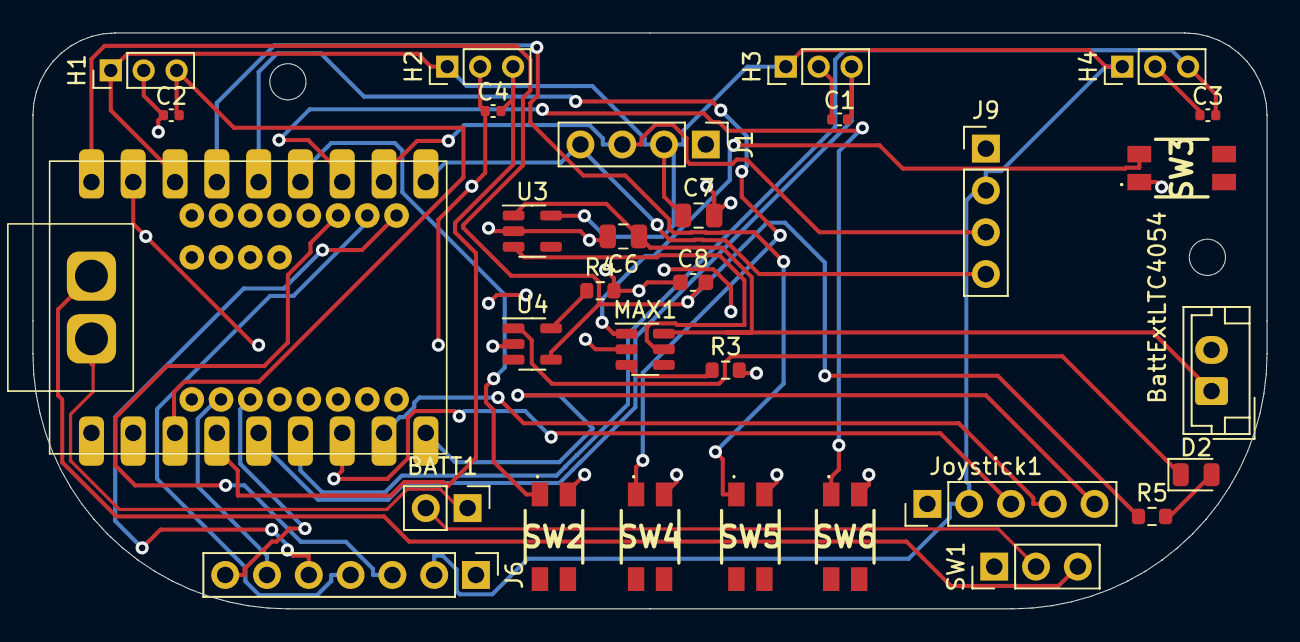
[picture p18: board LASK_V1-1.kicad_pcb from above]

Board: 2 copper layers, 75.0 x 35.0 mm, 33 parts (0 on the bottom side), 31 nets.

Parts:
BATT1: Conn_01x02_Pin; PinHeader_1x02_P2.54mm_Vertical
BattExtLTC4054: JST_02; JST_EH_B2B-EH-A_1x02_P2.50mm_Vertical
C1, C2, C3, C4: 100 nF; C_0402_1005Metric
C6, C7: 4.7uF; C_0805_2012Metric
C8: 2.2 uF; C_0603_1608Metric
D2: LED GREEN; LED_0805_2012Metric
H1, H2, H3, H4: A1369xUA-10; PinHeader_1x03_P2.00mm_Vertical
H7, H8: MountingHole; MountingHole_2.2mm_M2
J1, J9: Conn_01x04; PinHeader_1x04_P2.54mm_Vertical
J6: Conn_01x07_Pin; PinHeader_1x07_P2.54mm_Vertical
Joystick1: Conn_01x05_Pin; PinHeader_1x05_P2.54mm_Vertical
MAX1: SOT-23-6
R3: 1K; R_0603_1608Metric
R4: 2.7k; R_0603_1608Metric
R5: 150; R_0603_1608Metric
SW1: SW_SPDT; PinHeader_1x03_P2.54mm_Vertical
SW2, SW3, SW4, SW5, SW6: SW_Push; EVQP2P02M
U1: ESP32-S3-Super Mini
U3: TPS7A03; SOT-23-5
U4: LTC4054ES5-4.2; TSOT-23-5

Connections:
+3V3: C7.1, H1.1 (VCC), H2.1 (VCC), H3.1 (VCC), H4.1 (VCC), J1.2, J6.2, J9.2, Joystick1.2, U1.103 (3V3), U3.5 (OUT)
+3V8: BattExtLTC4054.1, C6.1, MAX1.6 (Vcc), U3.1 (IN)
+5V: C8.2, R5.1, U1.105 (5V), U4.4 (V_{CC})
BPACK+: BATT1.2, SW1.2 (B)
BPACK-: BATT1.1, U1.384 (BAT-)
BPACKSW+: SW1.3 (C), U1.385 (BAT+)
GND: BattExtLTC4054.2, C1.1, C2.1, C3.1, C4.1, C6.2, C7.2, C8.1, H1.2 (GND), H2.2 (GND), H3.2 (GND), H4.2 (GND), J1.1, J6.1, J9.1, Joystick1.1, MAX1.2 (GND), R3.2, R4.2, SW2.2, SW3.1, SW4.2, SW5.2, SW6.2, U1.100 (GND), U3.2 (GND), U4.2 (GND)
GP14: J6.5, U1.14
GP15: J6.4, U1.15
GP16: J6.3, U1.16
GP46: J6.7, U1.46
GP47: J6.6, U1.47
JSW: Joystick1.5, U1.7 (GP7)
JX: Joystick1.3, U1.5 (GP5)
JY: Joystick1.4, U1.6 (GP6)
LDO_EN: MAX1.5 (OUT), U3.3 (EN)
unnamed: D2.2 (A), R5.2
unnamed: D2.1 (K), U4.1 (~CHRG)
unnamed: MAX1.3 (CLEAR), R3.1
unnamed: R4.1, U4.5 (PROG)
RMT-BTN: MAX1.1 (In), SW3.2
SCL: J1.3, J9.3, U1.9 (GP9)
SDA: J1.4, J9.4, U1.8 (GP8)
b_left: SW4.1, U1.12 (GP12)
b_right: SW5.1, U1.13 (GP13)
b_select: SW6.1, U1.10 (GP10)
b_start: SW2.1, U1.11 (GP11)
hall_0: C2.2, H1.3 (VOUT), U1.1 (GP1)
hall_1: C4.2, H2.3 (VOUT), U1.2 (GP2)
hall_2: C1.2, H3.3 (VOUT), U1.3 (GP3)
hall_3: C3.2, H4.3 (VOUT), U1.4 (GP4)

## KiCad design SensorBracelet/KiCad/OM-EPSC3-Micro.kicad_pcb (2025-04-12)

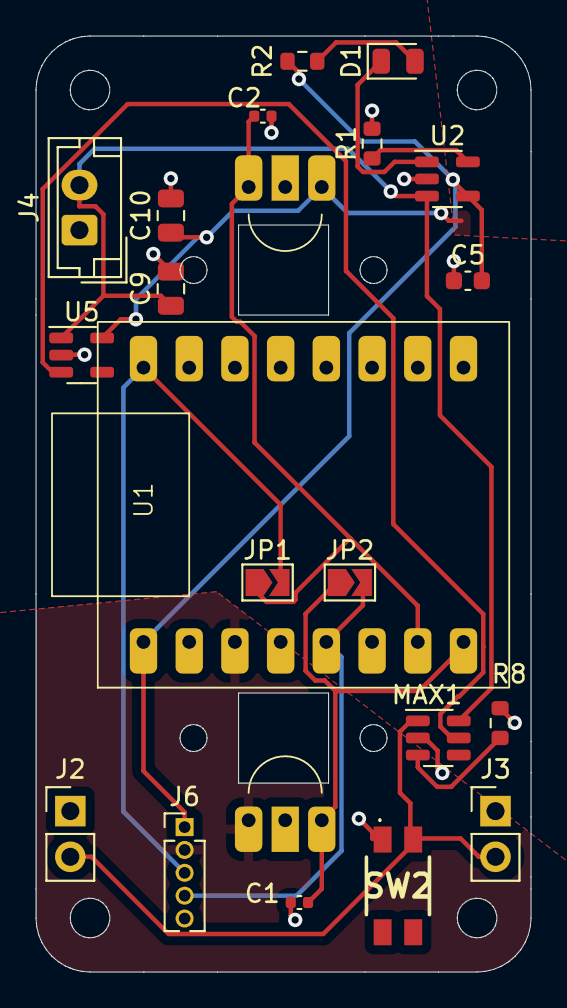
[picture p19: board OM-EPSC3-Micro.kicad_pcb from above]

Board: 2 copper layers, 27.5 x 52.0 mm, 22 parts (0 on the bottom side), 14 nets.

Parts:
C1, C2: 100 nF; C_0402_1005Metric
C5: 2.2 uF; C_0603_1608Metric
C9, C10: 4.7uF; C_0805_2012Metric
D1: LED GREEN; LED_0805_2012Metric
H0, H1: A1369xUA-10; Hall49E
J2, J3: Conn_01x02_Pin; PinHeader_1x02_P2.54mm_Vertical
J4: JST_02; JST_EH_B2B-EH-A_1x02_P2.50mm_Vertical
J6: Conn_01x05_Pin; PinHeader_1x05_P1.27mm_Vertical
JP1, JP2: SolderJumper_2_Open; SolderJumper-2_P1.3mm_Open_TrianglePad1.0x1.5mm
MAX1: SOT-23-6
R1: 2.7k; R_0603_1608Metric
R2: 150; R_0603_1608Metric
R8: 1K; R_0603_1608Metric
SW2: SW_Push; EVQP2P02M
U1: ESP32-C3-Super Mini
U2: LTC4054ES5-4.2; TSOT-23-5
U5: TPS7A03; SOT-23-5

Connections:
+3V3: C10.1, H0.1 (VCC), H1.1 (VCC), J6.2, U1.102 (3V3), U5.5 (OUT)
+3V8: C9.1, J4.1, MAX1.6 (Vcc), U2.3 (BAT), U5.1 (IN)
+5V: C5.2, J6.1, R2.1, U1.100 (5V), U2.4 (V_{CC})
ADC2: J6.4, JP2.2 (B), U1.3 (GPIO3)
ADC3: J6.3, JP1.2 (B), U1.5 (GPIO5)
GND: C1.1, C2.1, C5.1, C9.2, C10.2, H0.2 (GND), H1.2 (GND), J2.1, J3.1, J4.2, J6.5, MAX1.2 (GND), R1.2, R8.2, SW2.1, U1.101 (GND), U2.2 (GND), U5.2 (GND)
LDO_EN: MAX1.5 (OUT), U5.3 (EN)
unnamed: D1.2 (A), R2.2
unnamed: D1.1 (K), U2.1 (~CHRG)
unnamed: MAX1.3 (CLEAR), R8.1
unnamed: R1.1, U2.5 (PROG)
RMT-BTN: J2.2, J3.2, MAX1.1 (In), SW2.2
hall_0: C1.2, H0.3 (VOUT), JP2.1 (A), U1.0 (GPIO0)
hall_1: C2.2, H1.3 (VOUT), JP1.1 (A), U1.1 (GPIO1)

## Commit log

2024-10-26 Open Muscle Dev Kit Files V0 and V1
    Main files for the Open Muscle Dev Kit which consists of a Labeler and a Sensor Band.
    [LASK5-BatteryHolder.stl, LASK5-JoyThumb.stl, LASK5.csv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]
2024-10-27 Schematics and BOM
    [BOM for OpenMuscle Labeler V0.csv]
2025-04-12 Lask V2
    [BOM for OpenMuscle Labeler V1.csv, LASK5.kicad_pcb, LASK5.kicad_sch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]
2025-04-12 LASK5-V2 PCB
    [LASK-V2-0.kicad_pcb, LASK-V2-0.kicad_sch]
2025-04-13 LASK5-V2.1 Updates
    [LASK-V2-0.kicad_pcb, LASK5-2-1-Design-TESTTTT.dxf]
2025-05-07 LASK5 V2 Hardware Update
    Working PCB for LASK5 V2
    [LASK-V2-0-B_Cu.gbr, LASK-V2-0-B_Mask.gbr, LASK-V2-0-B_Paste.gbr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]
2025-05-07 LASK5 Hardware Revision V3 Proposal
    Hardware Revision: LASK5 V3 – USB Detection, Power-on Logic, Gyro Support, and ADC Accuracy Improvements
    Pull Request Summary:
    This proposed hardware update addresses limitations in the current LASK5 V2 schematic. The changes aim to improve usability, allow USB-powered operation without a battery, enhance ADC voltage reading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
2025-05-11 Or Power Switch Update
    [LASK5-2-1-Design-TESTTTT.dxf, LASK5-V3-0.kicad_pcb, LASK5-V3-0.kicad_sch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]
2025-05-19 LASK5 V3 and OM-FlexGrid
    [EDI2CAP.CFG, ICM-42688-P.stp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]

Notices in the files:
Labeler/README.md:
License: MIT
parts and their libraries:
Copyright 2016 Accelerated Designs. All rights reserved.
